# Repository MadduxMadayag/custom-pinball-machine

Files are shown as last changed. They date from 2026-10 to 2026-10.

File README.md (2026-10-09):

# Custom Arduino Pinball Machine

**A fully assembled, SpongeBob-themed pinball machine combining embedded control, sensor interfacing, electromechanical actuators, and custom mechanical design.**

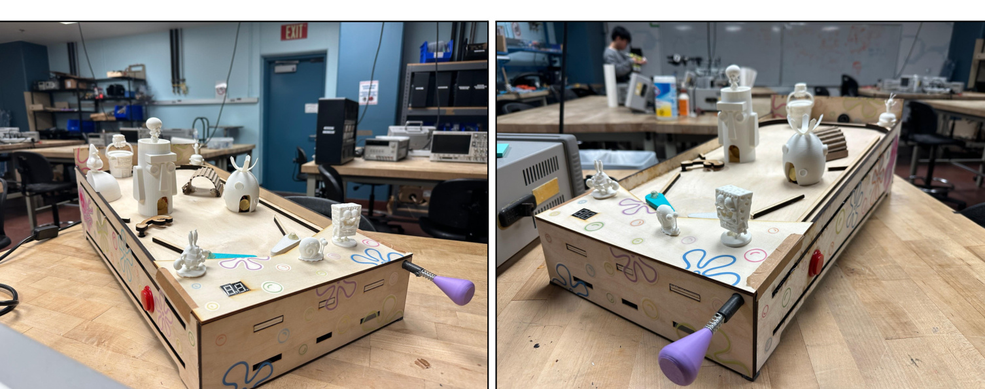
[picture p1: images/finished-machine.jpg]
Completed tabletop pinball machine


## Overview

Designed and built a tabletop pinball machine for **ECE 115**. The system uses an Arduino to coordinate player-controlled solenoid flippers, impact-based scoring, infrared ball detection, a servo-operated ball-return gate, animated obstacles, audio feedback, and a multiplexed two-digit score display. The playfield and mechanical assemblies were developed in **SolidWorks** and fabricated with plywood and 3D-printed components.

The project brings together **circuit design, embedded programming, mechanical CAD, fabrication, integration, and functional testing**.

## Features

| Subsystem | Implementation |
| --- | --- |
| Player controls | Two push buttons and solenoid-actuated flippers |
| Ball launching | Spring-loaded plunger |
| Scoring | Piezoelectric impact sensors inside character houses and an IR beam sensor at the Krusty Krab |
| Ball return | Optical drain detection and servo-driven gate mechanism |
| Moving obstacles | DC motor and RC servo mechanisms |
| Feedback | DFPlayer Mini audio playback and two multiplexed seven-segment displays |
| Controller | Arduino sketch implementing sensor processing, scoring, debouncing, and game-state logic |
| Mechanical design | SolidWorks assemblies, plywood structure, and printed figures |

## Finished Build

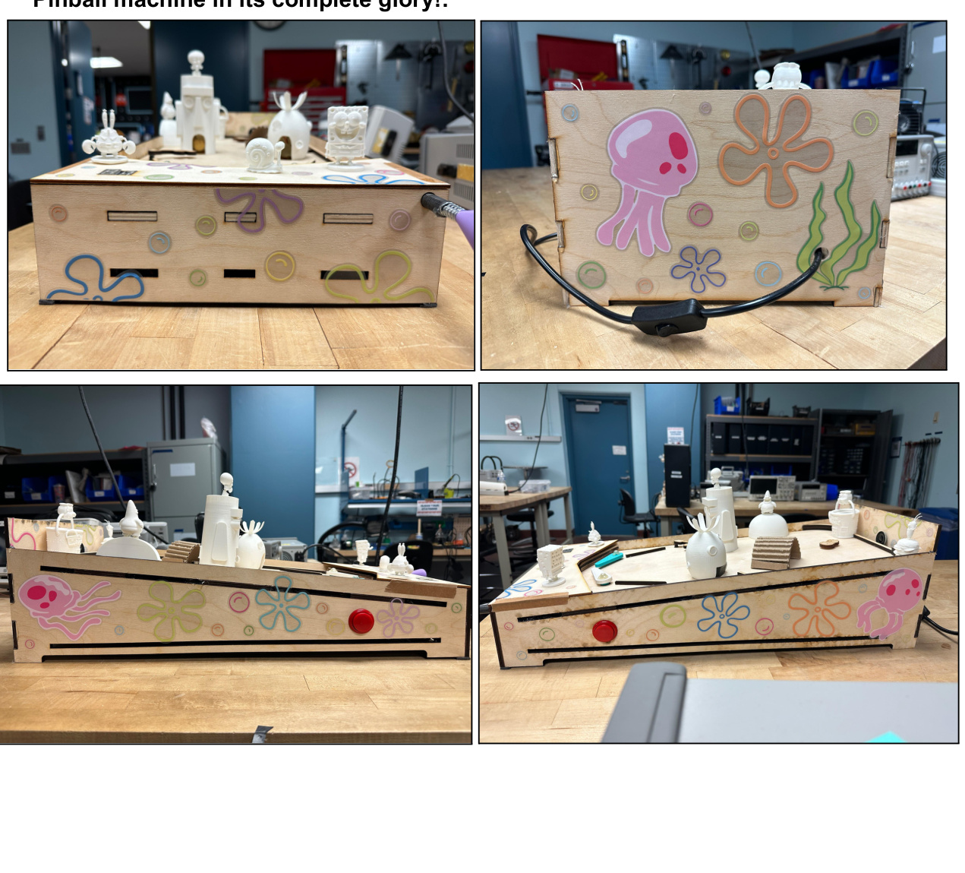
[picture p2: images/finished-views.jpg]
Final machine from multiple angles


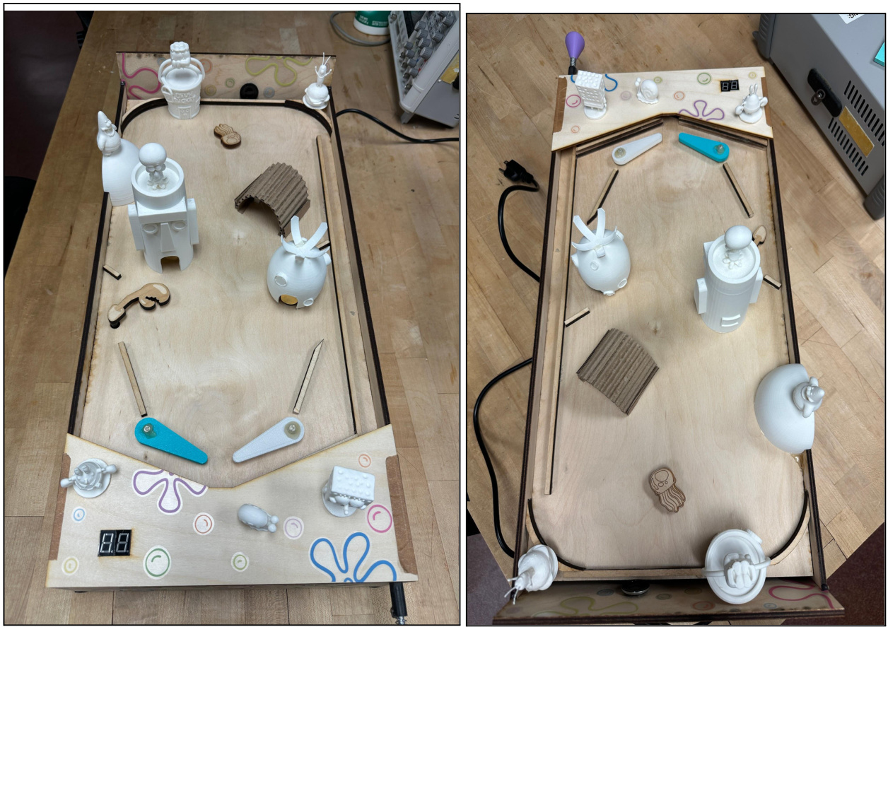
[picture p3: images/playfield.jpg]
Top-down playfield


The sloped playfield uses flippers and themed obstacles to keep a launched ball in play. The design also includes a physical ball launcher, a gate for ball reloading, and an accessible electronics area underneath the playfield.

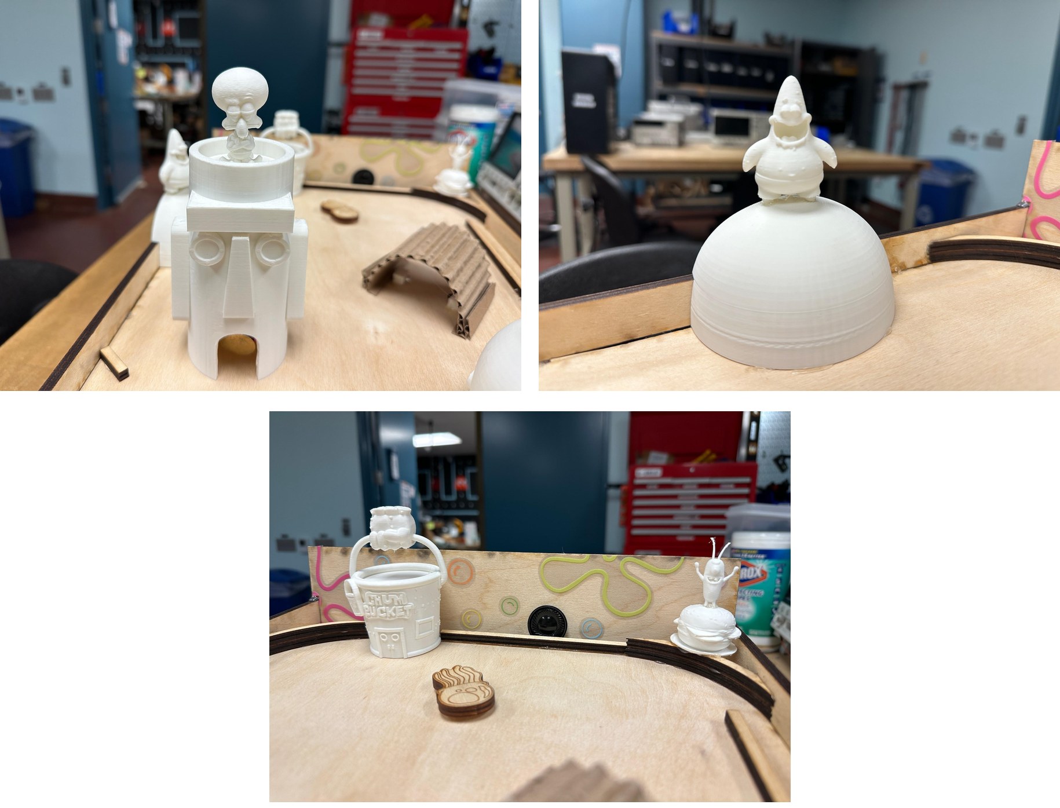
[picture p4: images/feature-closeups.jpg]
Close-ups of themed obstacles and scoring features


## Electrical and Embedded Design

The Arduino reads the **piezo** and **infrared** sensors to detect scoring events and ball movement. MOSFET driver stages switch the solenoids and motor, with flyback diodes used for inductive-load protection. The IR interface uses signal filtering and comparator hysteresis to help reject false triggers. A **DFPlayer Mini** provides audio cues, while the score is shown on two multiplexed seven-segment displays.

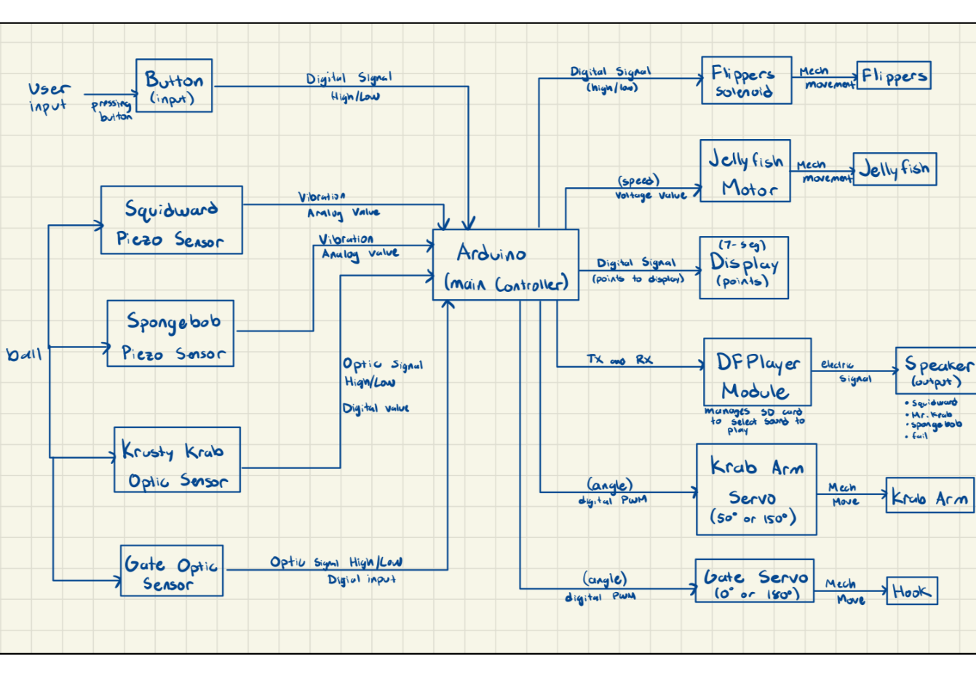
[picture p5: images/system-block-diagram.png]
System block diagram


**Actuation circuits — DC motor and solenoid flippers**

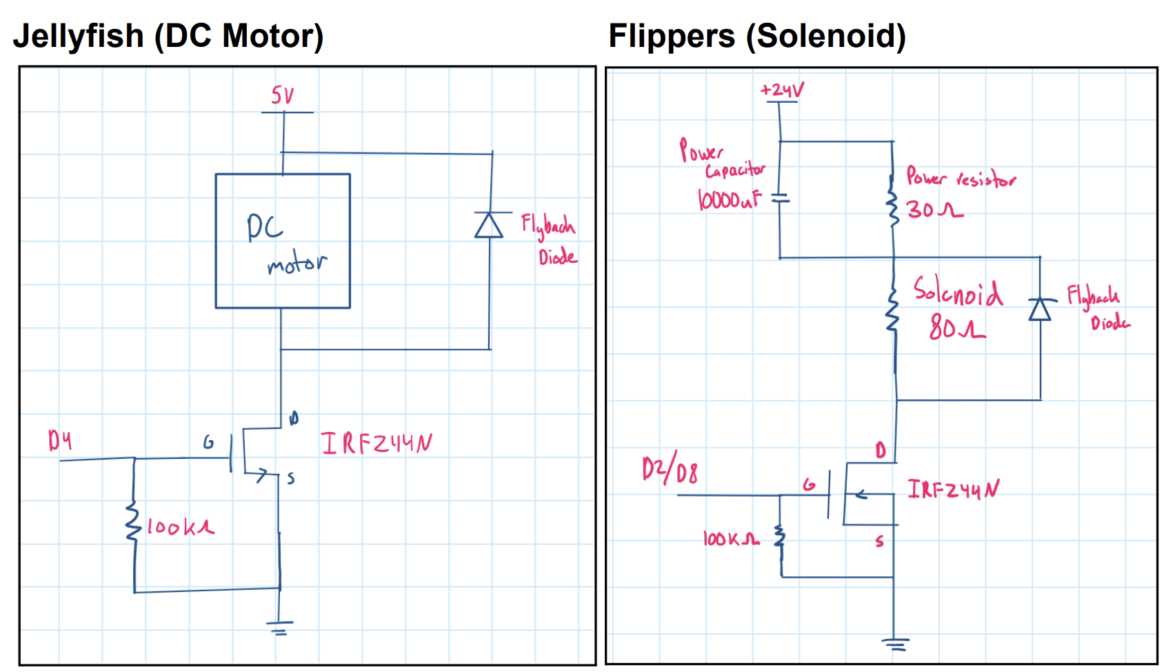
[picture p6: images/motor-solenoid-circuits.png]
Actuator circuit diagrams


**Sensor, audio, and display interface diagrams**

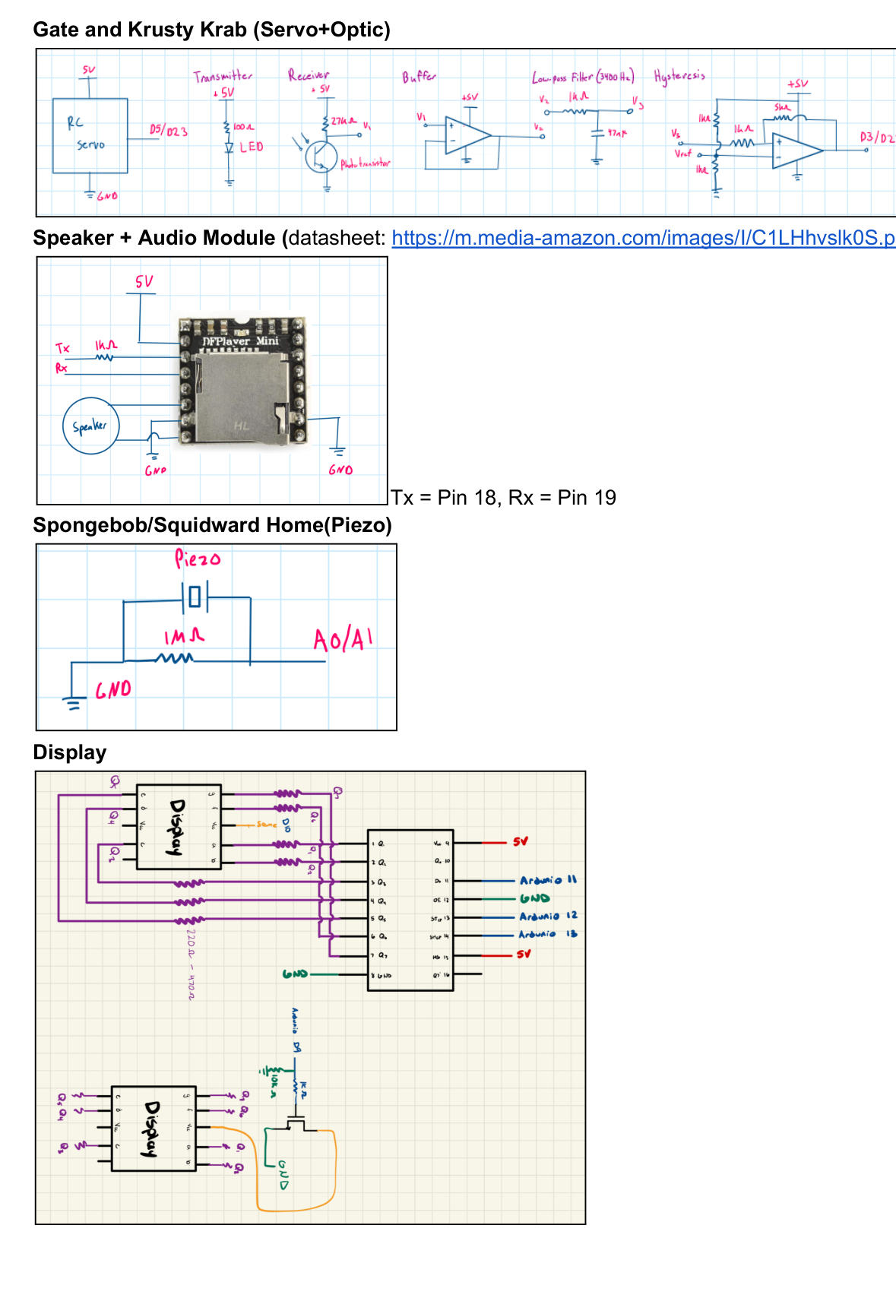
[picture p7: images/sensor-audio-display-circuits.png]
Sensor and display diagrams


See the original [`firmware/Pinball_code.ino`](firmware/Pinball_code.ino) for control logic. The sketch depends on the Arduino `Servo` library and the `DFRobotDFPlayerMini` library; hardware-specific pin assignments are defined near the top of the file.

## Mechanical Design

The team modeled the playfield, flippers, ball launcher, and moving mechanisms in **SolidWorks** before constructing the plywood enclosure and assembling the printed figures. Native assembly and part files are preserved in [`mechanical/`](mechanical/).

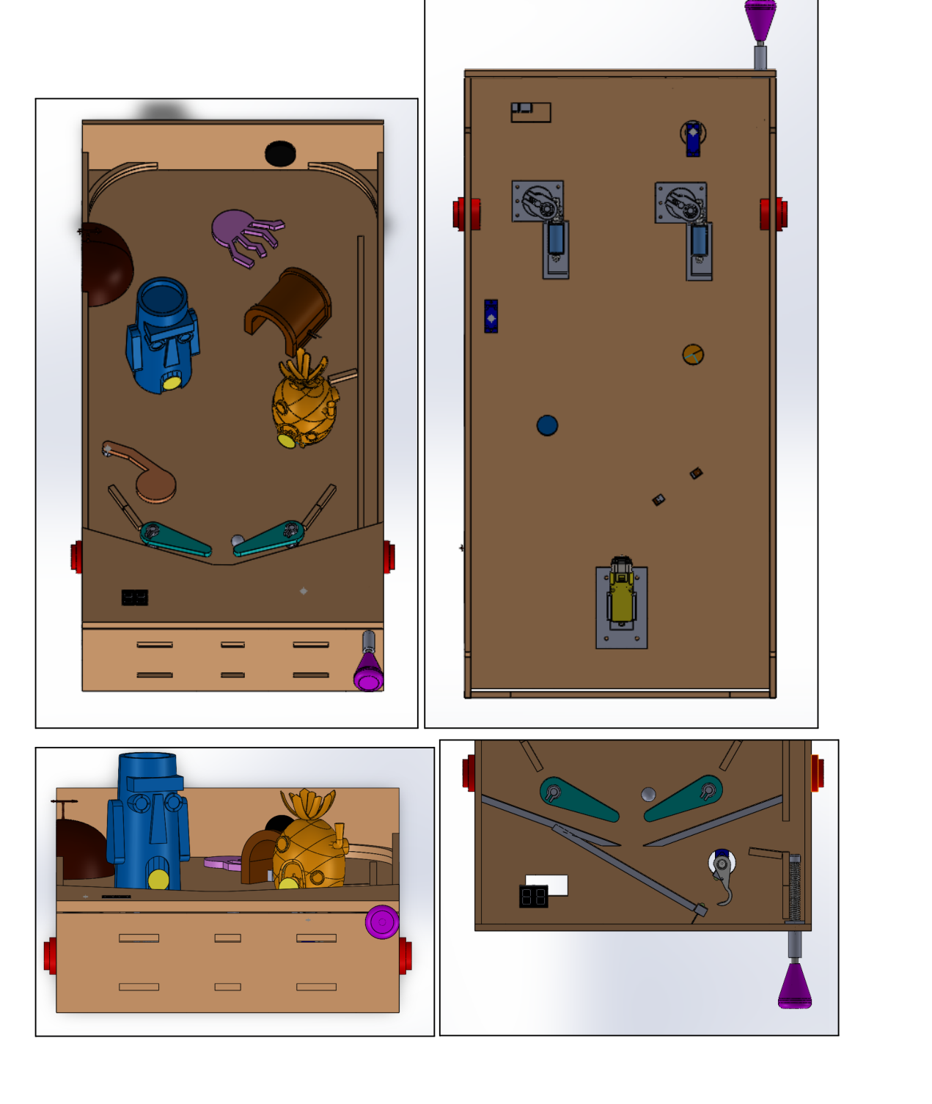
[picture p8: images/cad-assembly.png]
CAD assembly views


**Electronics mounted beneath the playfield**

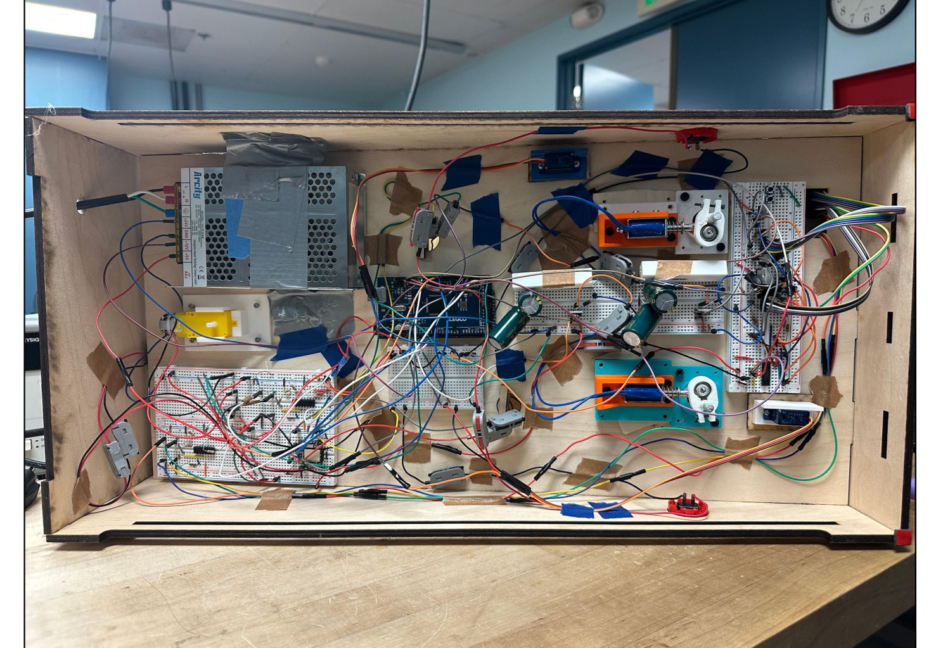
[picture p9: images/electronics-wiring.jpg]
Wiring and electronics mounted under the machine


The electronics were attached to the underside of the playfield and enclosure sides rather than using separate breadboard mounts, keeping wiring shorter and the hardware accessible during integration.

## Game Control

The Arduino coordinates scoring, flipper movement, ball detection, and servo-based reloading through game-state logic. The report documents the high-level state-machine diagrams for the pinball machine, score display, flipper controls, and player flow.

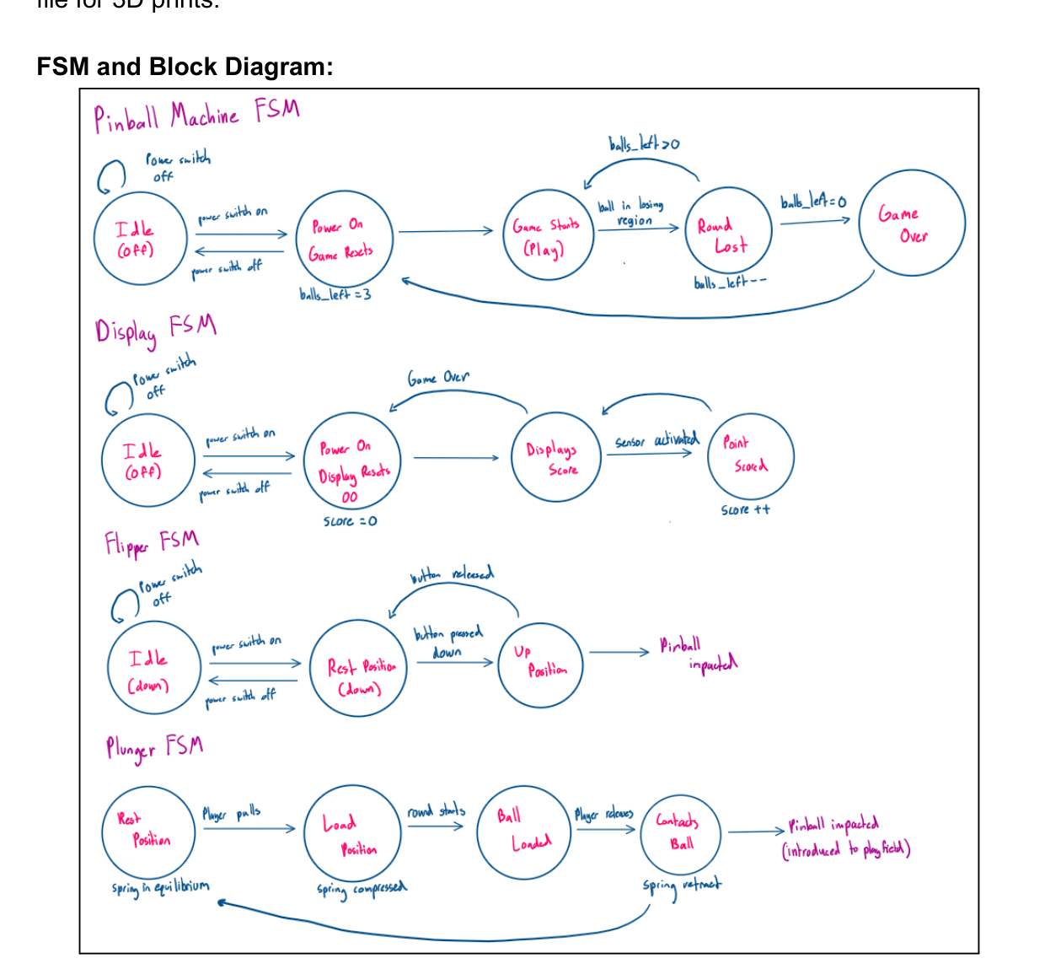
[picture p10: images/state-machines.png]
Finite-state-machine diagrams


The optical and servo gate mechanism was also designed and evaluated as a dedicated subsystem.

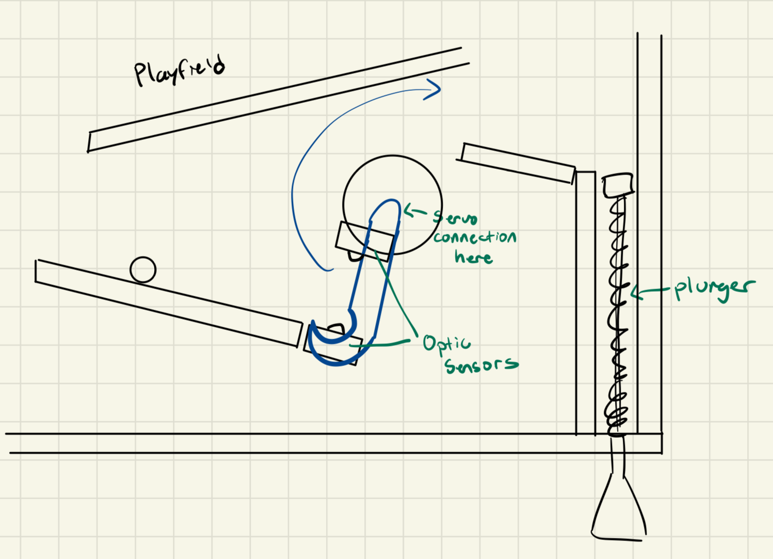
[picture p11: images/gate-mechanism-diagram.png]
Gate mechanism design diagram


## Testing and Results

The final team report documents a **completed system evaluation**, including the following functional observations:

- **Scoring:** Impacts on the piezo-equipped houses updated the score. The Squidward sensor required more force than the SpongeBob sensor.
- **Ball return:** The gate successfully collected/reloaded a drained ball in the documented test.
- **Round handling:** The report records a three-cycle gate/round test.
- **Playfield design:** Added obstacles reduced immediate ball losses and extended rounds during playtesting.

These are qualitative functional results from the final report, not quantified reliability or performance benchmarks. See the [final report](documentation/final-report.pdf), especially its test matrix on **pages 5–6**.

## Project Files

```text
custom-pinball-machine/
├── README.md
├── images/             # Selected photographs and figures from the final PDF
├── firmware/           # Original Arduino sketch
├── mechanical/         # SolidWorks assemblies and part files
│   └── printed-figures/# Original 3MF assets (check third-party licensing)
└── documentation/      # Original 13-page final report
```

**Image sources:** Finished-machine and playfield photos are from report **pages 6–7**; close-up figures from **page 2**; underside wiring from **page 3**; CAD from **page 8**; FSM diagrams from **page 9**; electrical diagrams and system overview from **pages 10–11**; and gate mechanism diagrams from **page 5**. The images are included separately for easier viewing on GitHub.

## Contributors

**Maddux Madayag and Eric Zheng** — ECE 115 team project.

## Notes

- The firmware is preserved as provided. It was designed for the team's original controller, pinout, wiring, and audio assets; this repository is **not** a plug-and-play kit.
- The **sound files are not included**, and hardware-specific libraries and dependencies must be installed separately.
- The `.SLDPRT` / `.SLDASM` files may require SolidWorks or compatible software, and all their referenced components must be available for assemblies to resolve.
- Some themed `.3mf` figures may have external authors or separate licenses; verify permissions and attribution before public reuse.

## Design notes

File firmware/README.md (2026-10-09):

# Arduino Firmware

`Pinball_code.ino` is the original team sketch, preserved without modifications.

## Dependencies
- `Servo.h` — Arduino Servo library
- `DFRobotDFPlayerMini.h` — DFRobot DFPlayer Mini library

The firmware uses `Serial1` for the audio module and pin definitions at the start of the sketch. Choose a board with the required pins and hardware serial interface, and check those pin definitions against the wiring diagrams in `documentation/final-report.pdf` before flashing. The SD card audio files referenced by `playFolder()` are not included in this repository.

This is an archive of the working course design, **not a validated portable build configuration**. The final report records system testing; no automated compilation or hardware test is included here.

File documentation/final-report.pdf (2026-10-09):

Eric Zheng | Maddux Madayag
A17338793 | A17444726
ECE115 - Module5

Google Drive folder containing files: https://drive.google.com/drive/folders/1A8mDtq7jwpapd6mcWQVZRQ9MVMisnB0y?usp=sharin g (https://drive.google.com/drive/folders/1A8mDtq7jwpapd6mcWQVZRQ9MVMisnB0y?usp=sharing)

# 5.2.1 Add the proposed functionality to the pinball machine

## Completed additional function

Added functions: more obstacles, decals*, piezo circuitry, gate mechanism, more 3D printed figures, and compacted wire system
*reference final pinball machine photos

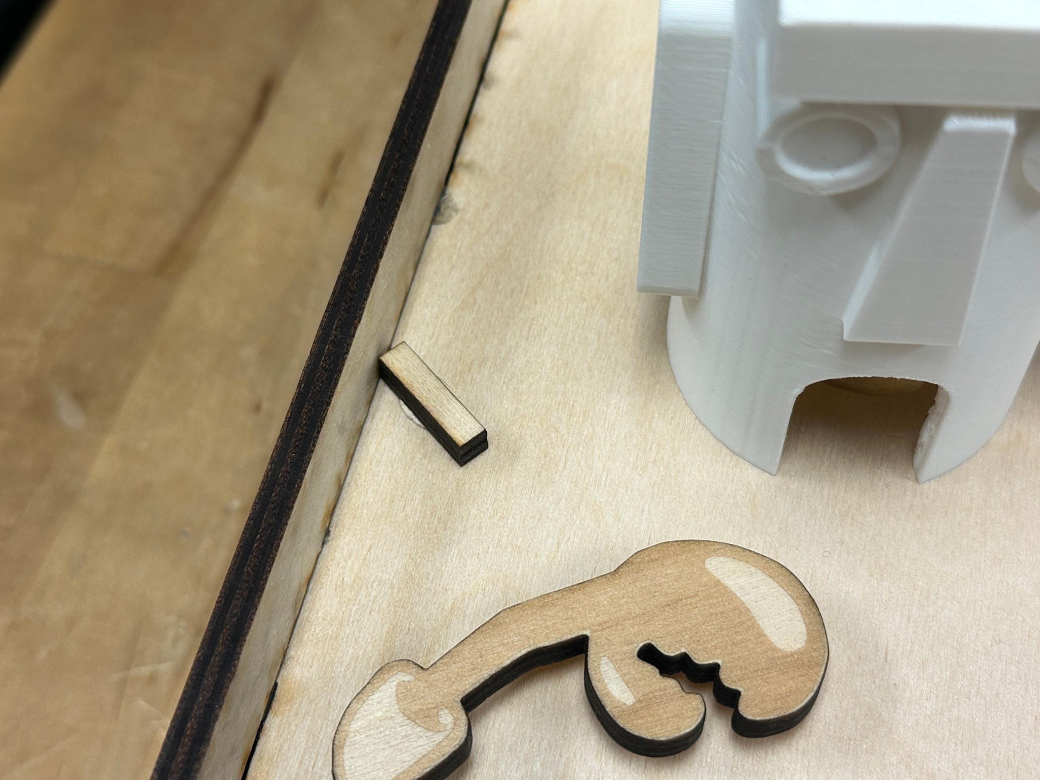
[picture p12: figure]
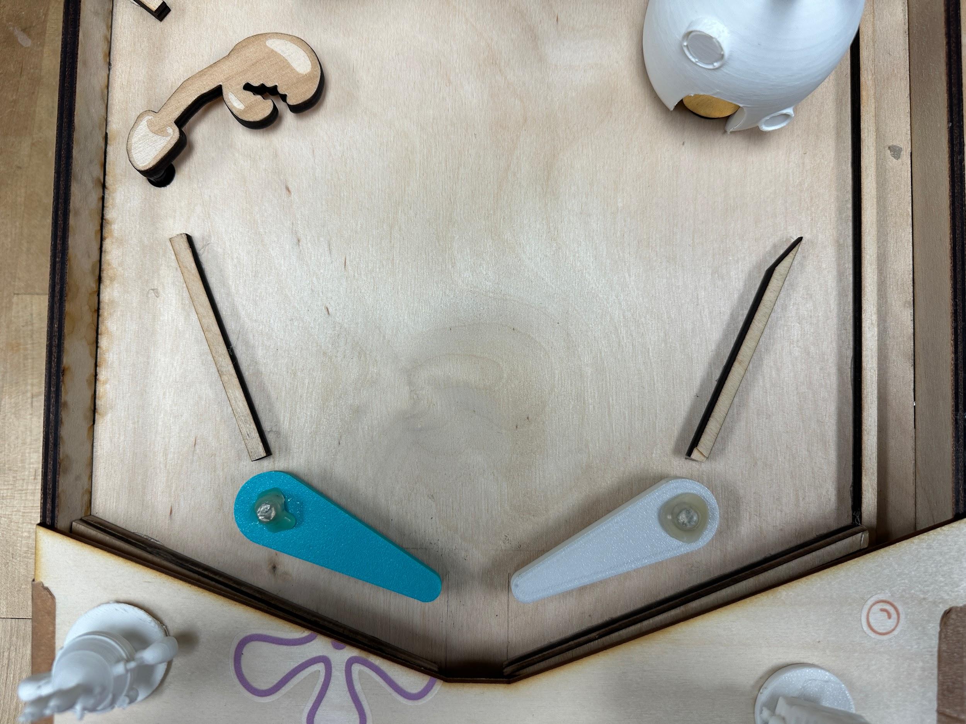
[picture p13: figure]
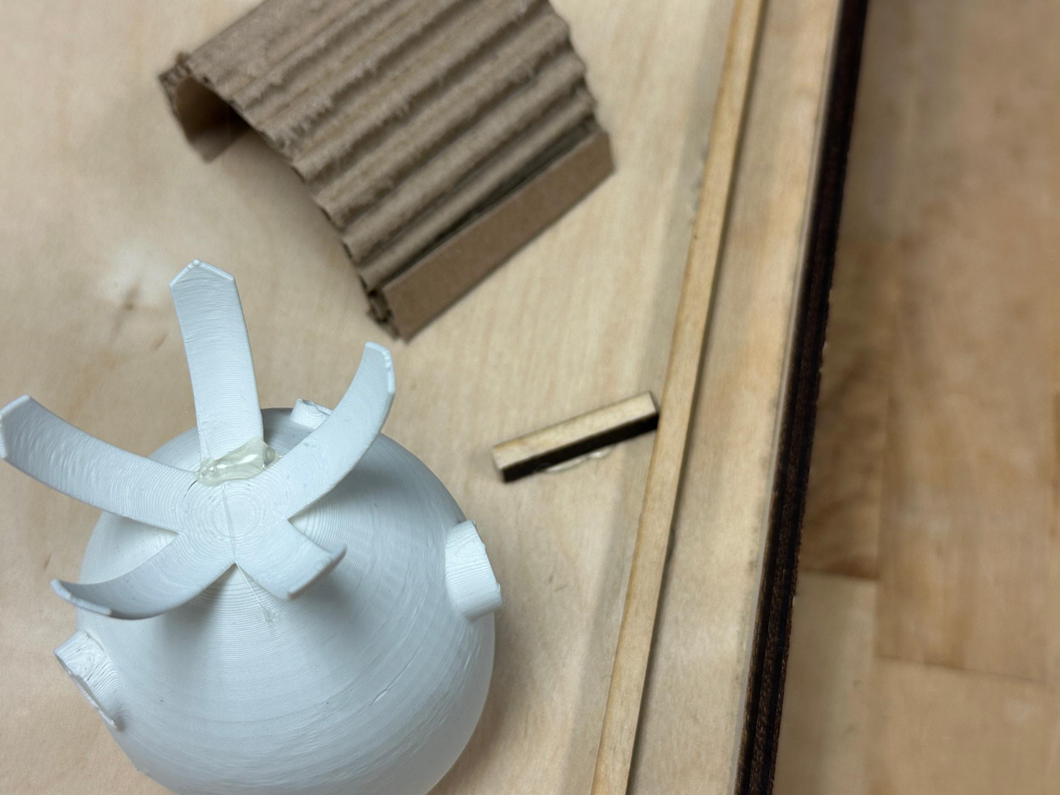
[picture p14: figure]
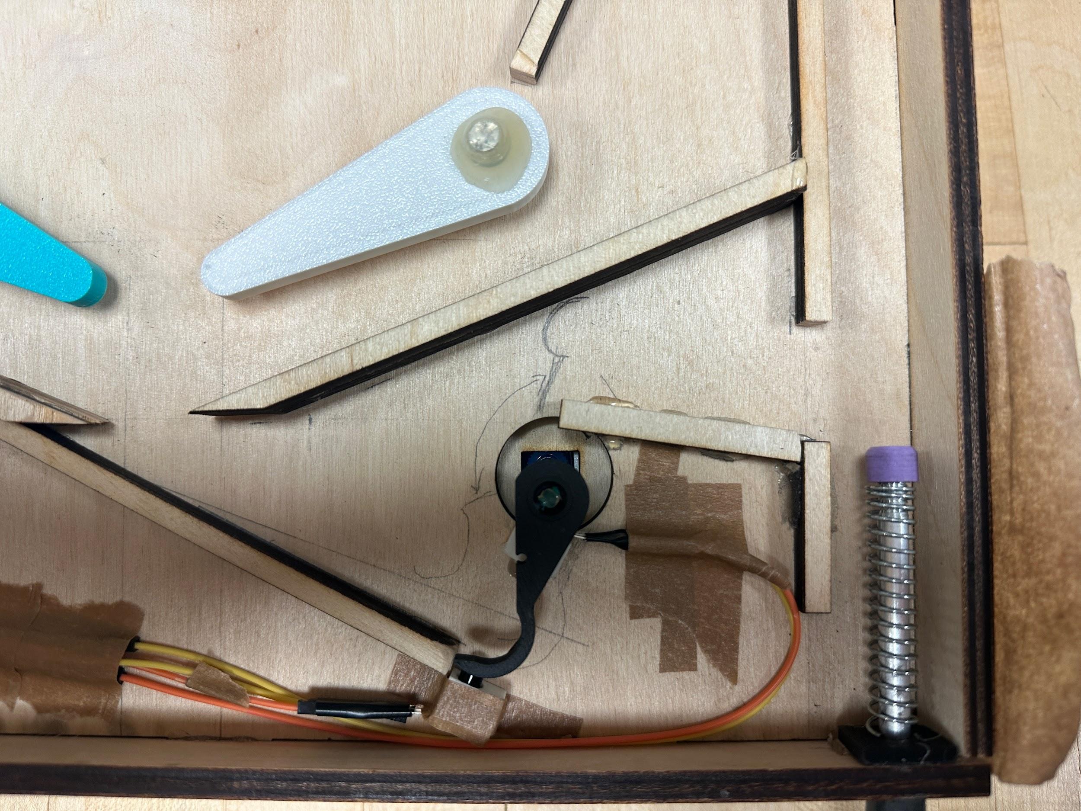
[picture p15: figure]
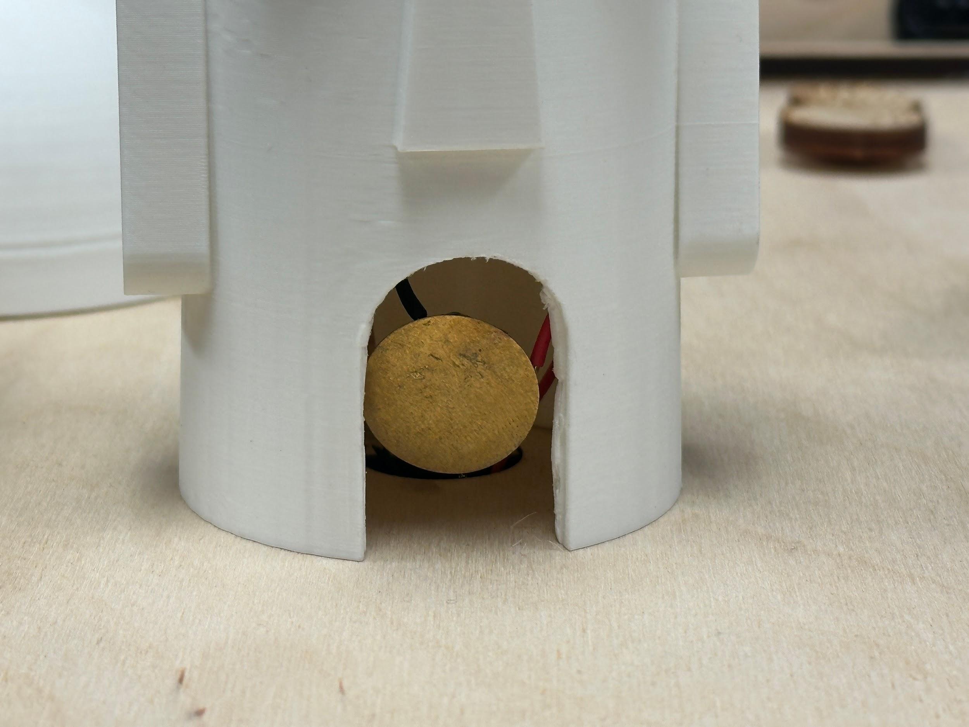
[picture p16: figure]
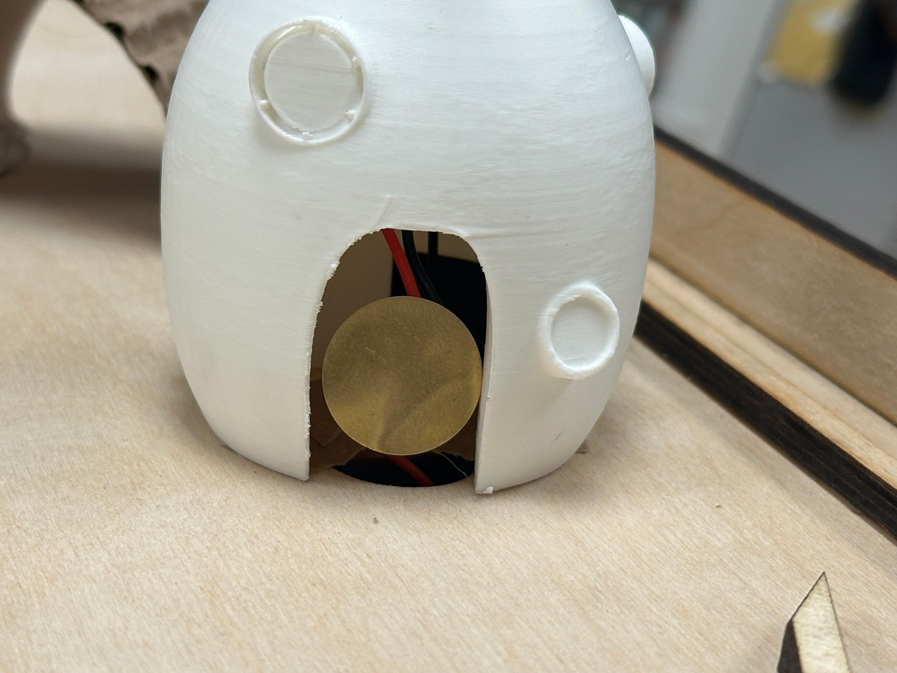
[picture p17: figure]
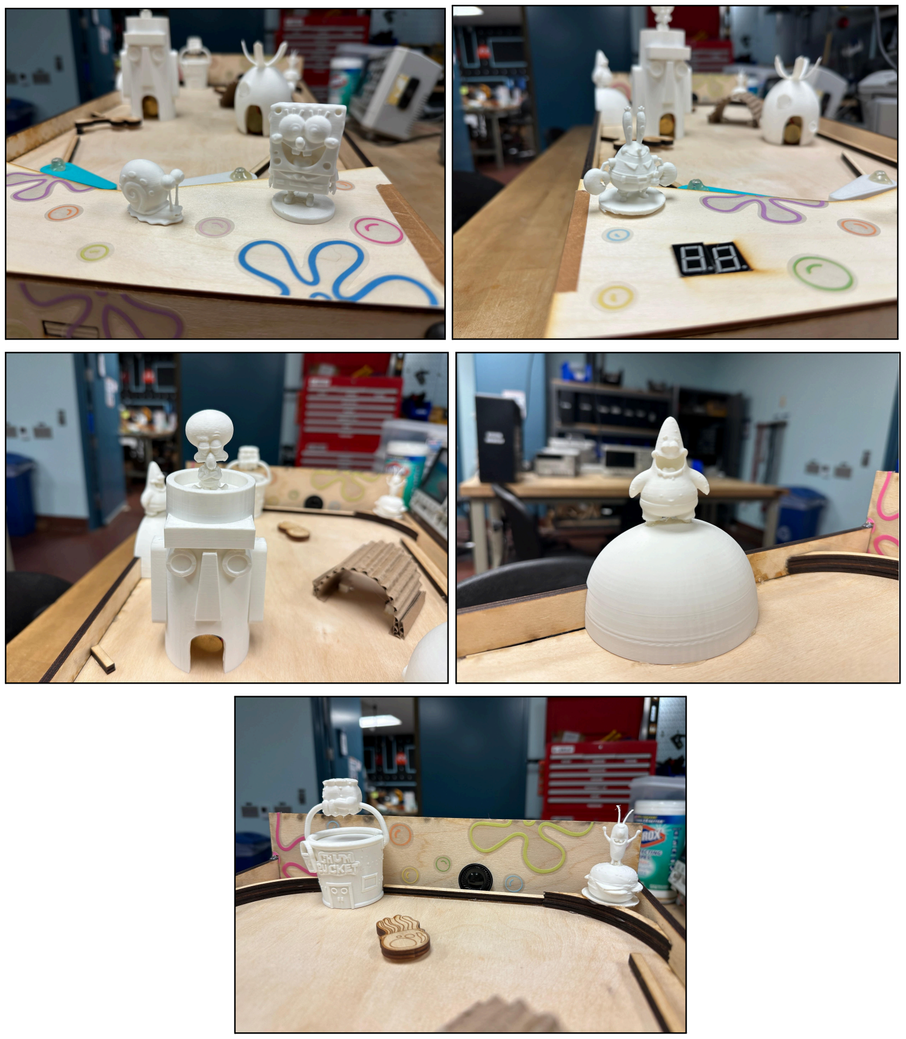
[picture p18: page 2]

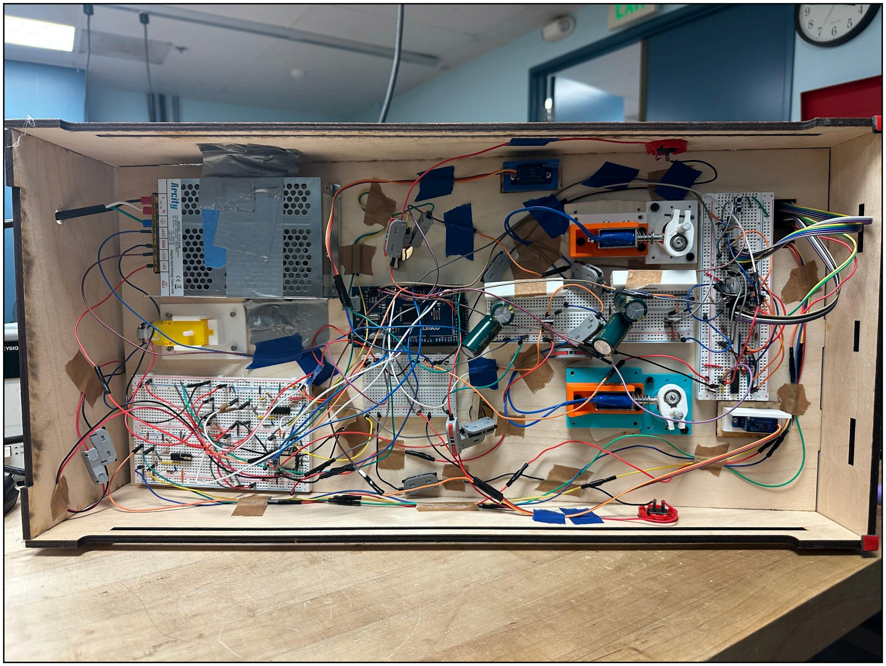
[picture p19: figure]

Additional Functionality Omitted:
- 3D mounts for the arduino and breadboards: required longer wires for routing and created the challenge of switching between working on the top (playfield) and circuits. Switches approach by containing electronics by attaching them to the opposite of the playfield and sides of the pinball machine.
- Paint: Would take too long for paint to dry so we opted to use other techniques to improve the visuals of the pinball machine (more 3D printed figures and decals)

# 5.2.2 Final Presentation / Demo

## Full System Evaluation: Complete

# 5.2.4 Final Writeup

## Final Writeup

### 1. Summarize your additional functionality

Additional Functionality:
We originally proposed the added functionality of 3D printed breadboard and motor holders. However, we found that it was easier to mount the electronic components to the opposite side of the playfield and the sides, as this kept the electronics accessible when working on the top and shortened the wire lengths. One additional functionality we implemented was adding extra walls to prevent the ball from easily reaching the losing region. Furthermore, we were able to integrate piezo sensors into our system and develop an RC servo arm to load the ball into the plunger. In our proposal, we also planned to paint the pinball machine, but due to time constraints we were not able to complete this. Instead, we 3D printed SpongeBob themed figures and applied decals to make the system more visually appealing.

Requirements:
1. Flipper obstacles make losing harder
2. Piezo Sensor sensing ball well
3. Automatic gating
4. Decal doesn’t obstruct playfield Materials:
- 0.275” plywood: Amazon (https://www.amazon.com/s?k=1%2F4+inch+plywood)
- Decals: Amazon (https://www.amazon.com/dp/B0FD7F2FVL)
- 3D and laser prints: Free from ECE Makerspace
- Model files:
https://drive.google.com/drive/folders/1kOY6Z7JHsXjdMh7Nvi-niw0s6ZCll8pl?usp=sharing (https://drive.google.com/drive/folders/1kOY6Z7JHsXjdMh7Nvi-niw0s6ZCll8pl?usp=sharing)
Design:
Piezo

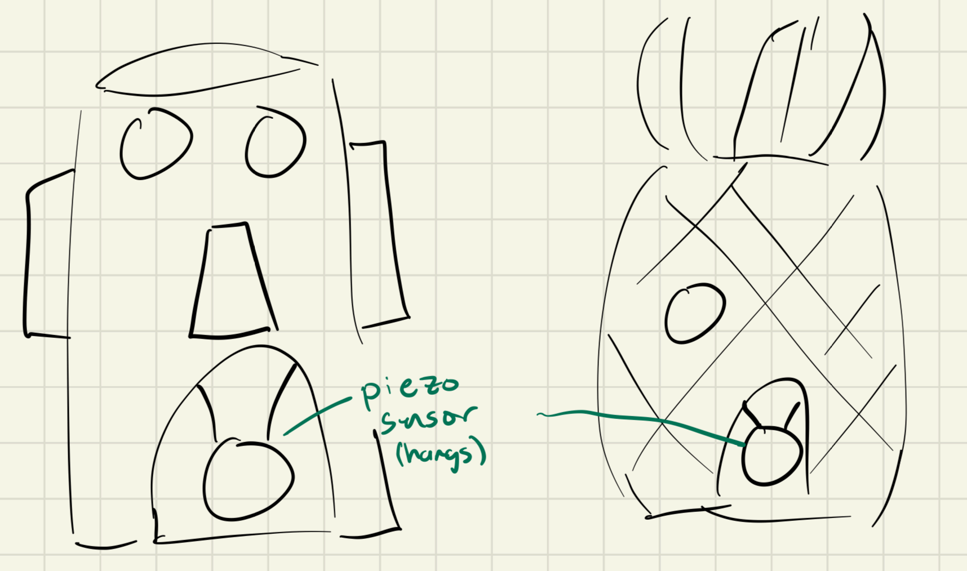
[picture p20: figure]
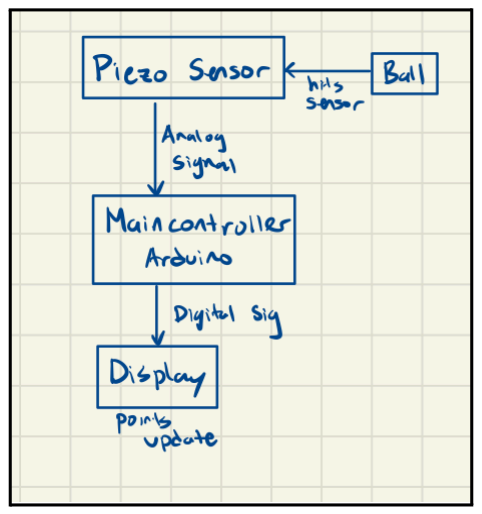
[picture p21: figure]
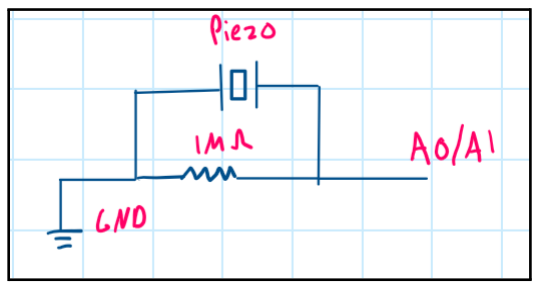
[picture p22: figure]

Gating Mechanism

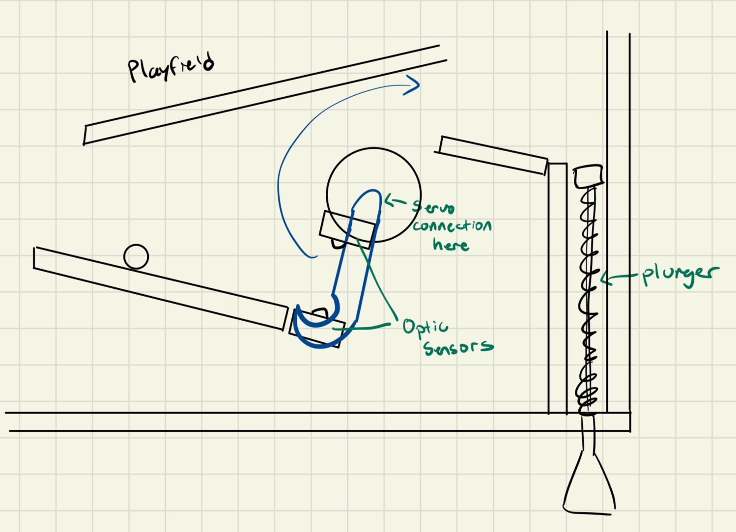
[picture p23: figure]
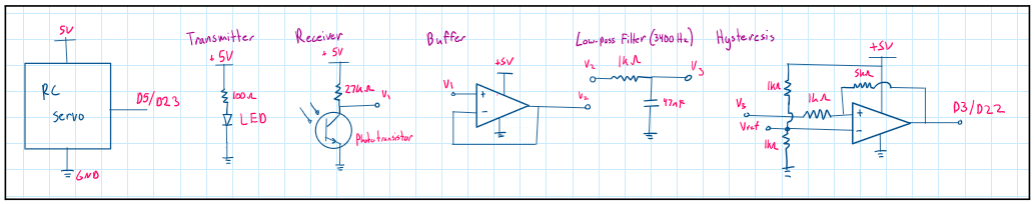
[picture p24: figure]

Trace Matrix:

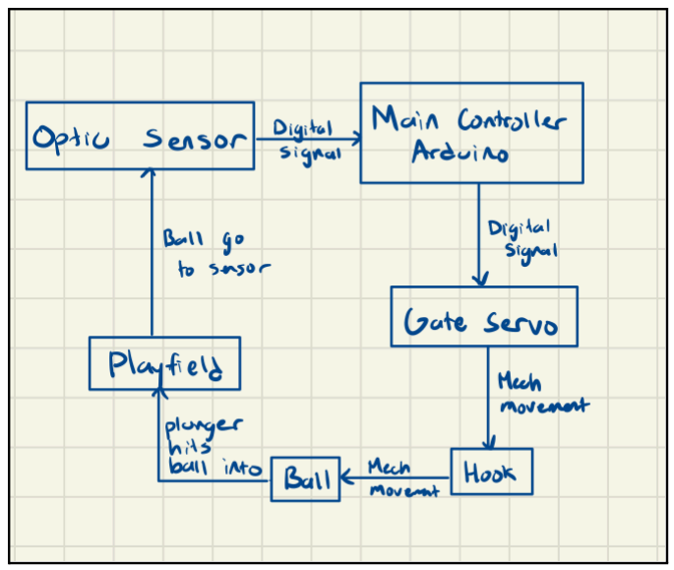
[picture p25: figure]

Specification number | Specification description | Test to perform | Relevant requirement | Specification (units) | Measured value (units)
1 | Functionality | Launch the ball using the flipper into the piezo sensors, see if score updates. | 2 | Yes/No (Y/N) | Y, the squidward sensor seems to be less sensitive than spongebob and requires more force for it to update the display.
2 | Functionality | Let the ball fall towards the bottom of the board and see if the gating mechanism will pick up the ball and load it in the launcher. | 3 | Yes/No (Y/N) | Y
3 | Functionality | Let the gating mechanism load the ball 3 times, and let the ball fall towards the gating mechanism again, and see when the gating mechanism stops. | 3 | count | 3

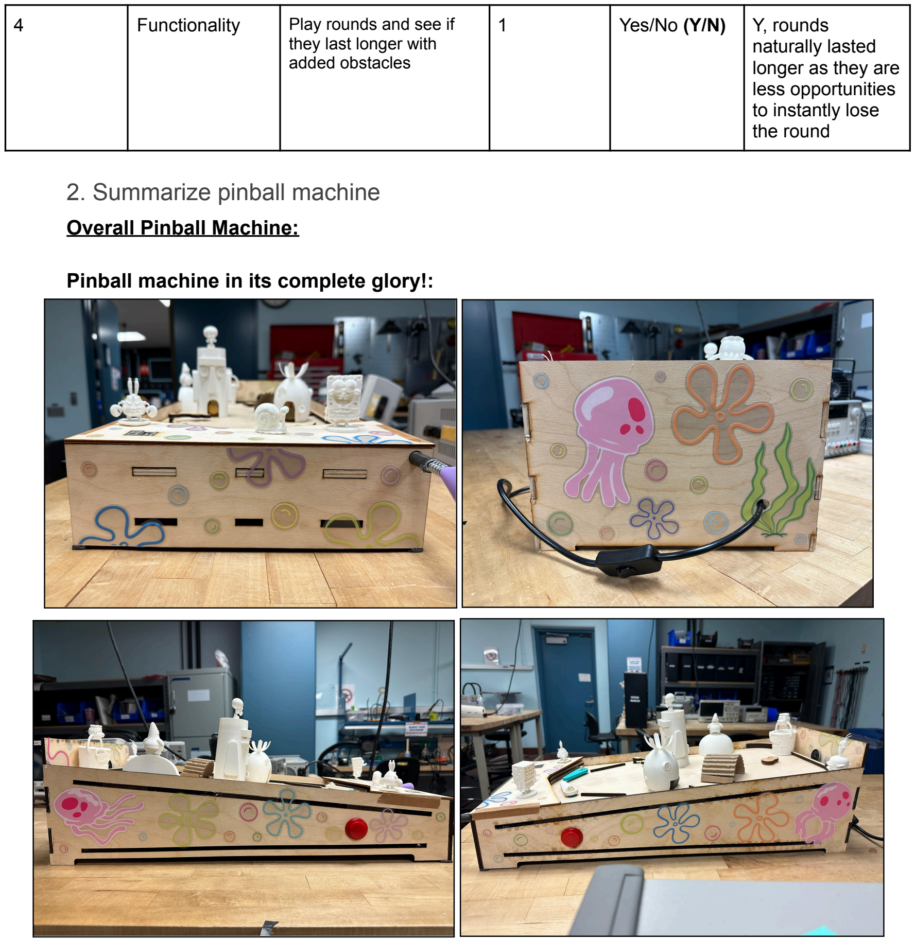
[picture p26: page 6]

4 | Functionality | Play rounds and see if
they last longer with
added obstacles
1 | Yes/No (Y/N) | Y, rounds
naturally lasted
longer as they are
less opportunities
to instantly lose
the round

### 2. Summarize pinball machine

Overall Pinball Machine:

Pinball machine in its complete glory!:

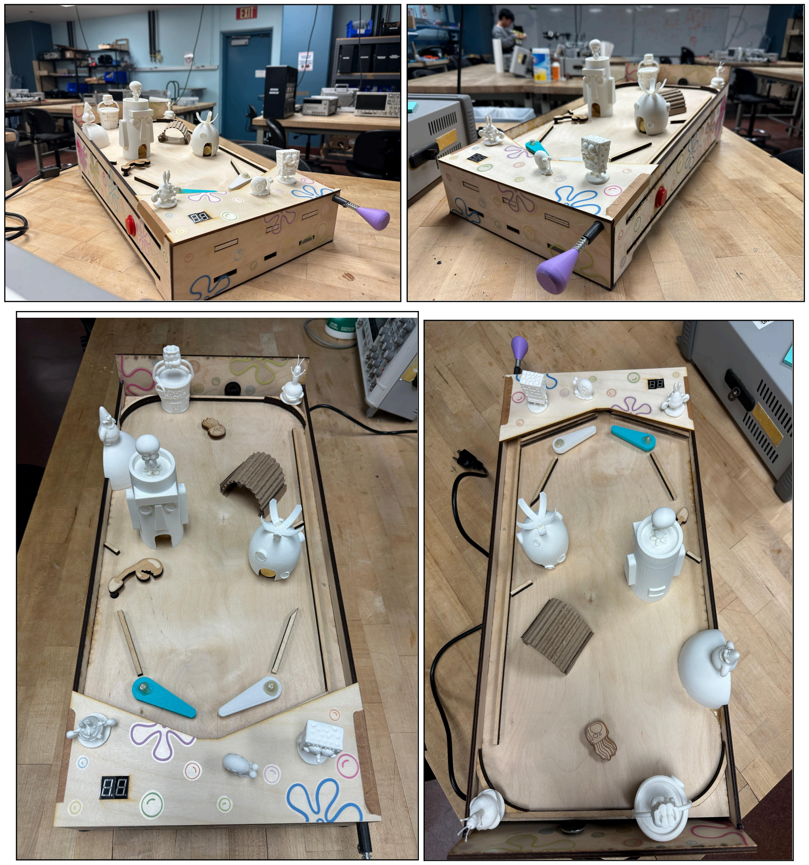
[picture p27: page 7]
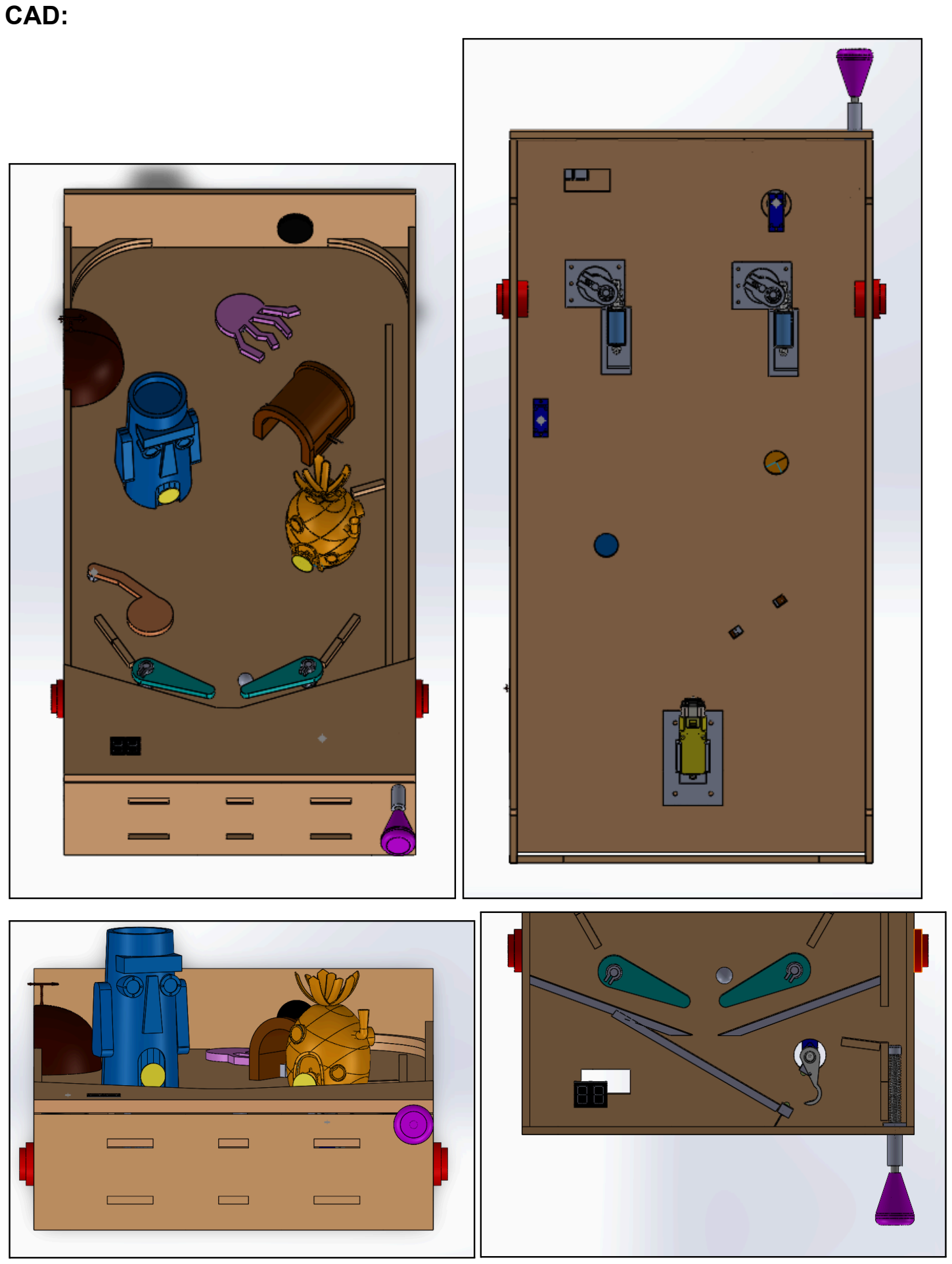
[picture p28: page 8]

CAD:

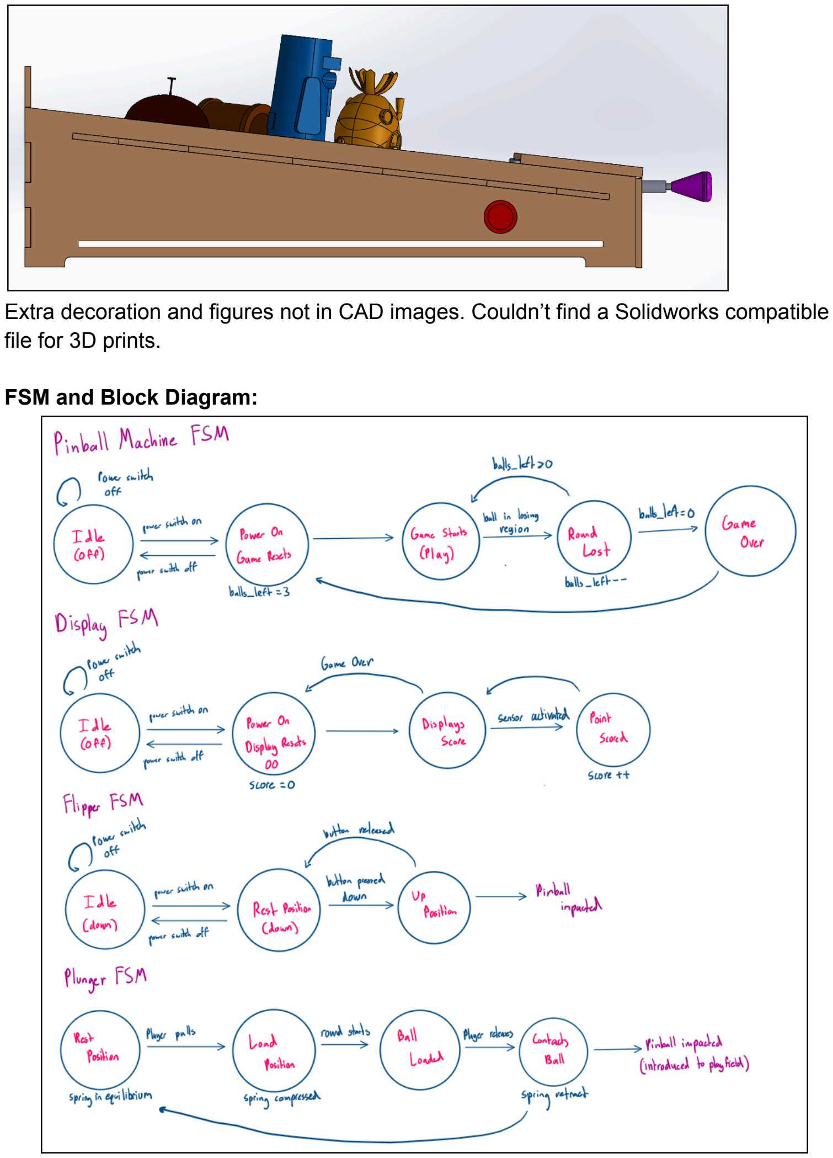
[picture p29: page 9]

Extra decoration and figures not in CAD images. Couldn’t find a Solidworks compatible file for 3D prints.

FSM and Block Diagram:

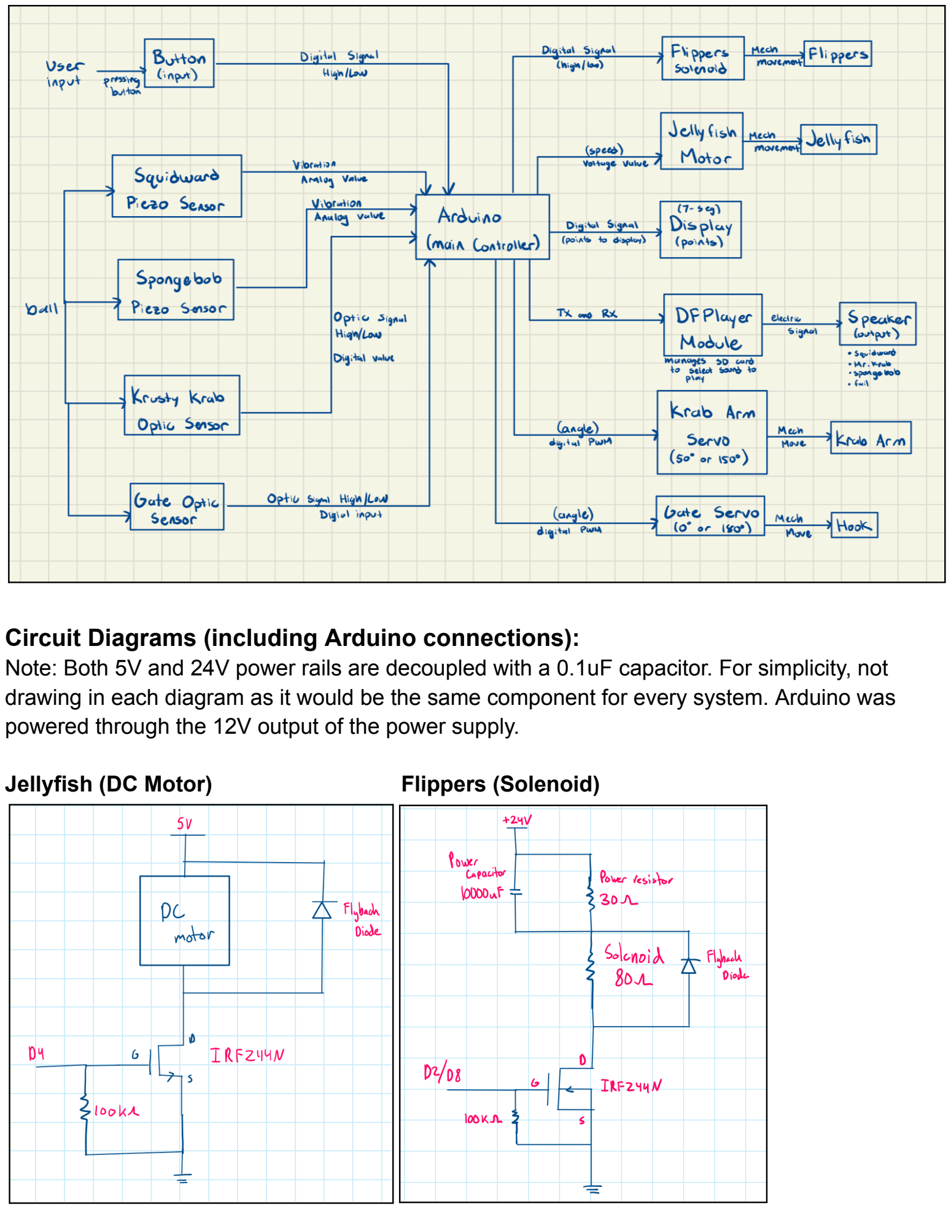
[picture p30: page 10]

Circuit Diagrams (including Arduino connections):
Note: Both 5V and 24V power rails are decoupled with a 0.1uF capacitor. For simplicity, not drawing in each diagram as it would be the same component for every system. Arduino was powered through the 12V output of the power supply.
Jellyfish (DC Motor) | Flippers (Solenoid)

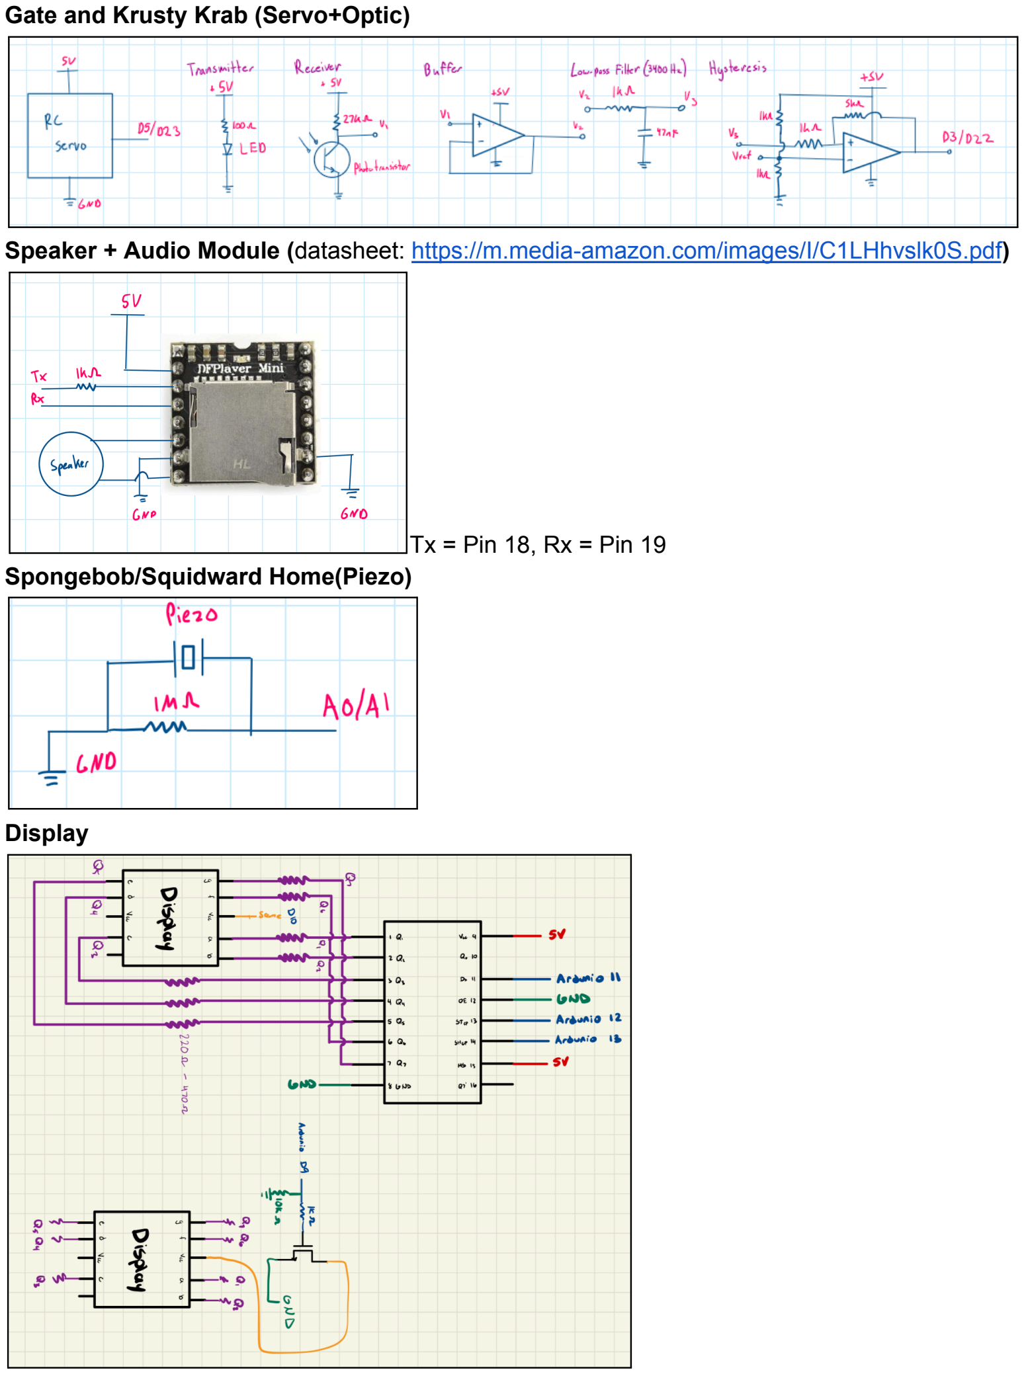
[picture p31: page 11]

Gate and Krusty Krab (Servo+Optic)

Speaker + Audio Module (datasheet: https://m.media-amazon.com/images/I/C1LHhvslk0S.pdf)

Tx = Pin 18, Rx = Pin 19
Spongebob/Squidward Home(Piezo)

Display

Pinball Machine Summary:
Our pinball machine was constructed primarily from plywood with several 3D printed components and electronics and hardware provided by the class. The playfield is slanted so the ball naturally rolls towards the losing region. A spring loaded plunger launches the ball onto the playfield, and two solenoid driven flippers allow the player to redirect the ball and keep it in play. Obstacles on the board include plywood walls, 3D printed SpongeBob themed houses, and plywood shapes of a jellyfish and Mr. Krab’s arm are attached to an RC servo and DC motor. All components share a common ground with bypass capacitors across the power rails to stabilize supply. Comparing the CAD model with the final built machine highlights the importance of accurate modeling when translating a design into a physical system.

Points are earned through several sensor systems. Piezo sensors inside Squidward’s and SpongeBob’s houses detect impacts from the ball and produce voltage spikes that are read by an Arduino analog input. An IR emitter and receiver inside the Krusty Krab detect when the ball passes between them, awarding points and trigger Mr. Krab’s arm (attached to RC servo) to move between positions. This detection circuit uses an op-amp buffer, low pass filter, and hysteresis comparator to reduce noise and prevent false triggers.

Another IR emitter and receiver pair detects when the ball reaches the losing region, allowing the Arduino to track rounds and reset the game when the ball is reloaded and both flipper buttons are pressed. The DC motor and solenoids are controlled using power MOSFETs so the Arduino can safely switch higher current loads. A pull down connection on the MOSFET gate ensures the device turns off if the Arduino disconnects, and flyback diodes across the motor and solenoids suppress inductive voltage spikes. The solenoid circuit also includes a capacitor and resistor to control activation and safely discharge stored energy.

A DFPlayer Mini audio module plays SpongeBob themed sounds during gameplay, and two seven segment displays are multiplexed using MOSFET switching to show the score. All hardware interfaces with the Arduino, which coordinates sensor inputs and actuator outputs. The block diagram illustrates the connections between components, while the FSM diagram represents the high level game states and transitions that control gameplay.

### 3. Safety, Ethics, and Diversity:

Since we are working with circuits for this project, we ensured that nothing will catch fire from unsafe operation (overheating) or shorting. We made sure to always check the secureness and connection of the wires including a common ground reference point. Multiple wires were connected between subsystem grounds for redundancy. Since the pinball machine involves launching a ball at high speed from a plunger, we implemented several safety measures to prevent potential injuries. Springs were added on both ends of the plunger to better control the launch speed of the ball, and the walls of the machine were built high enough to prevent stray balls from leaving the playfield. We also sanded down any chipped or sharp edges on the machine to reduce the risk of splinters and make it safer for people to handle.We also respected the ECE Makerspace through proper usage of all equipment and following rules for the space.

On ethics, we were mindful of minimizing waste and responsibly using the shared class resources. We returned unused components so that other/future students could use them. We also tested our system carefully before demonstrations to avoid damaging equipment or creating unsafe conditions in the makerspace.

For diversity, our theme is Spongebob, a cartoon that is recognized around the world and familiar to many people. We hope that this theme helps make the project engaging for a broad audience. We also tried to design the machine so that the gameplay is simple and easy to understand, allowing people from different backgrounds or technical experience levels to interact with it.

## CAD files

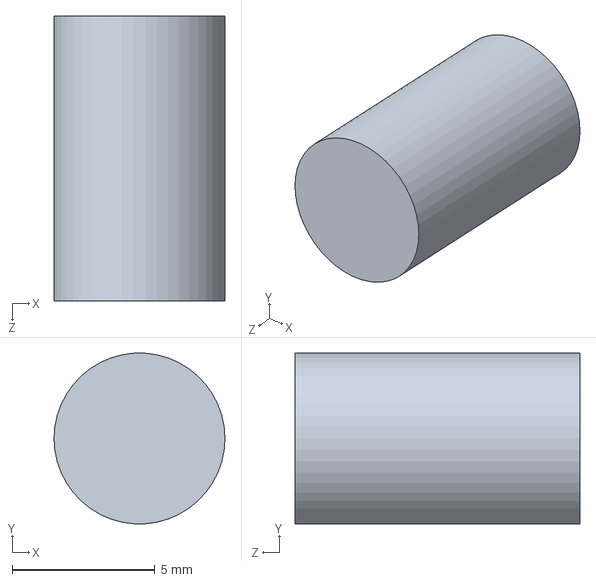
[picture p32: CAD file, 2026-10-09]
mechanical/Flipper/clamp_connect.SLDPRT
6.00 x 5.99 x 10.0 mm

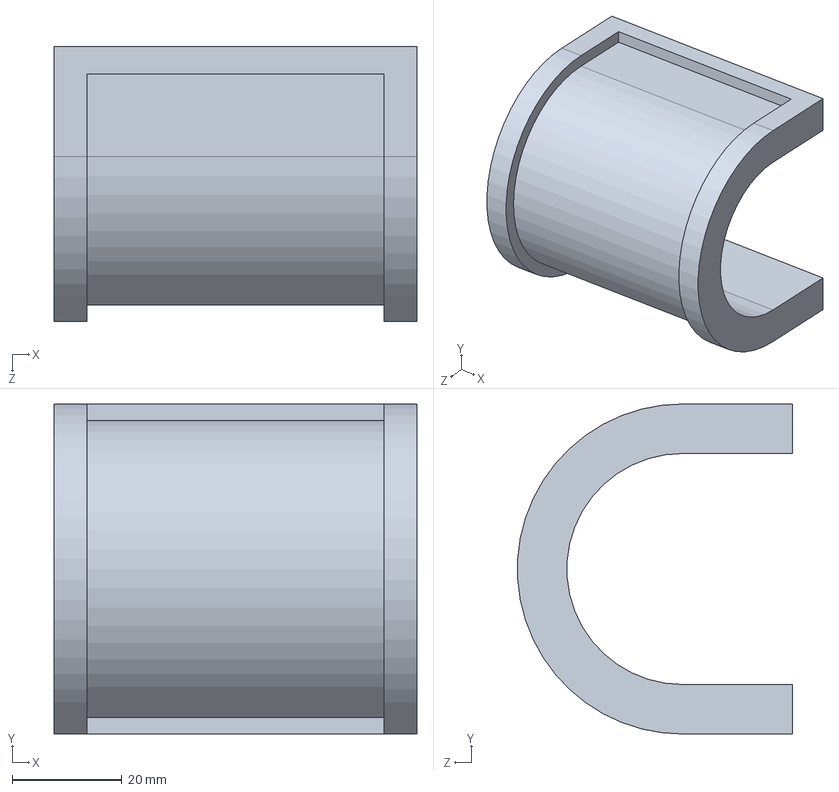
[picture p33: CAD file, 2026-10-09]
mechanical/Houses/krab.SLDPRT
66.0 x 60.0 x 49.9 mm

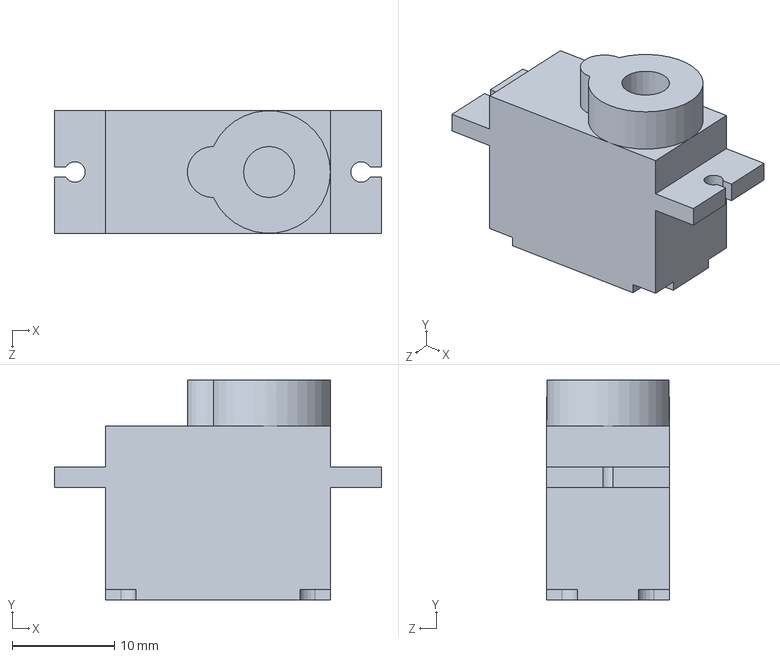
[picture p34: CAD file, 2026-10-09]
mechanical/Krab_Arm/Pieza1.SLDPRT
32.0 x 21.5 x 12.0 mm

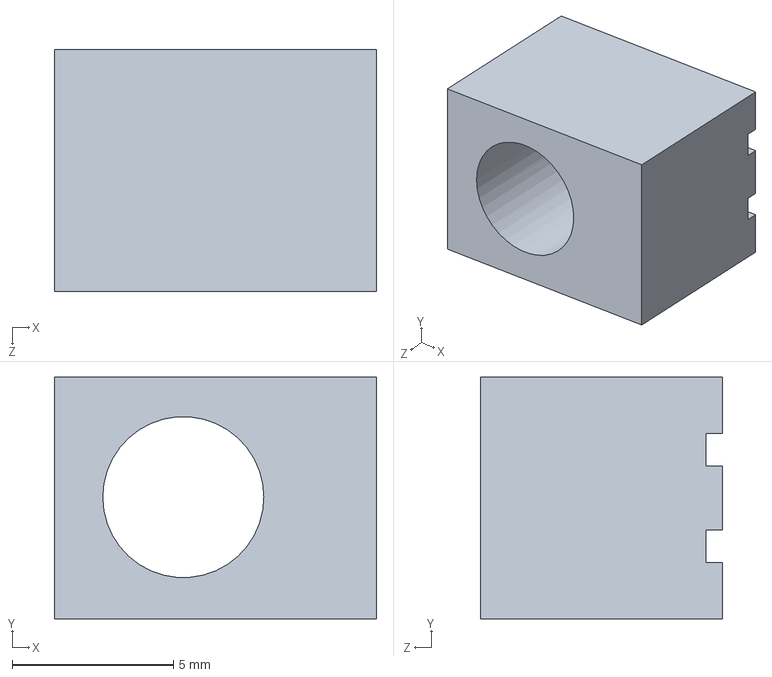
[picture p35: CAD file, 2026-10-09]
mechanical/LEDs/LED_holder.SLDPRT
10.0 x 7.50 x 7.50 mm

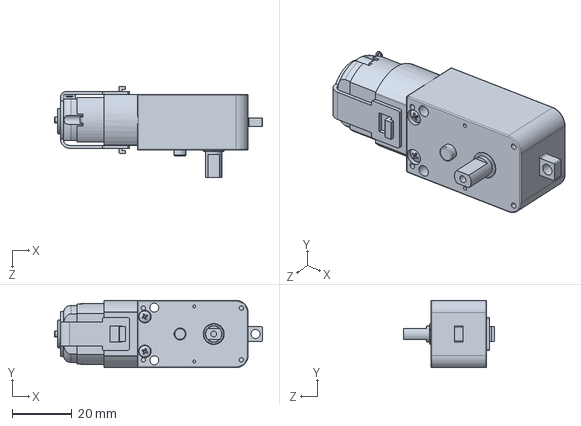
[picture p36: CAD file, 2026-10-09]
mechanical/Motor/motor.SLDPRT
69.5 x 22.4 x 30.5 mm

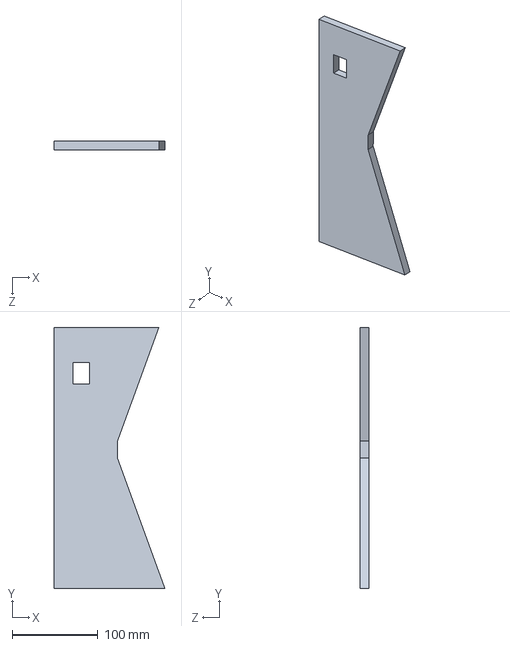
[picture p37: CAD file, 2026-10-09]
mechanical/Playfield/cover_hide.SLDPRT
129.5 x 304.8 x 10.0 mm

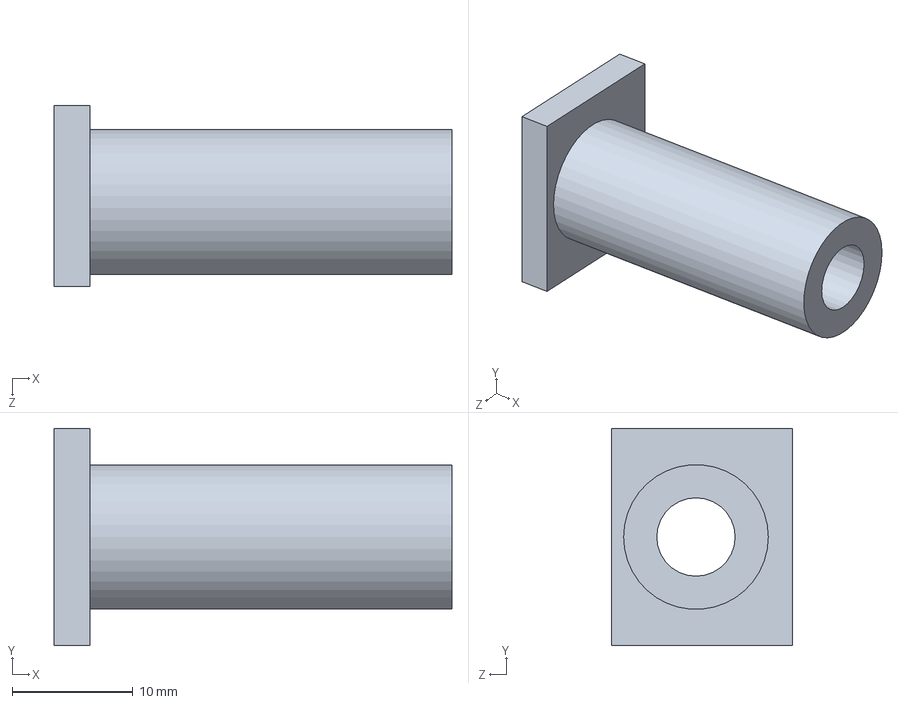
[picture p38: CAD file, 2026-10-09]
mechanical/Plunger/plunger_wall.SLDPRT
33.0 x 18.0 x 15.0 mm

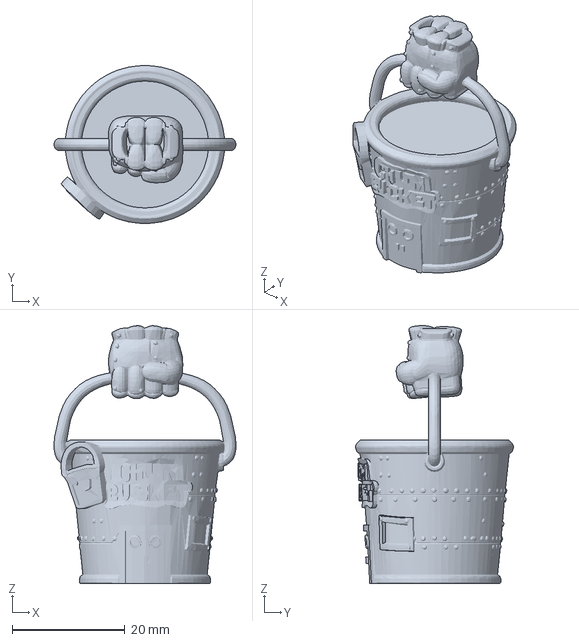
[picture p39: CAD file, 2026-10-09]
mechanical/printed-figures/chum-bucket.3mf
32.2 x 28.0 x 45.7 mm

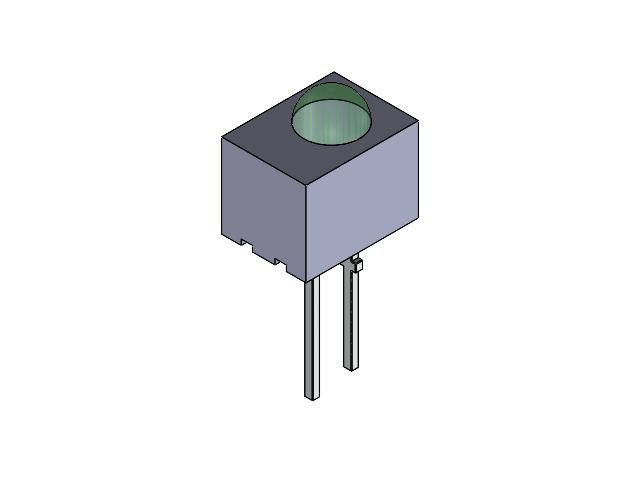
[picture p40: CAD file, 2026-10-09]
mechanical/LEDs/assembled_LED.SLDASM
LED
LED_holder

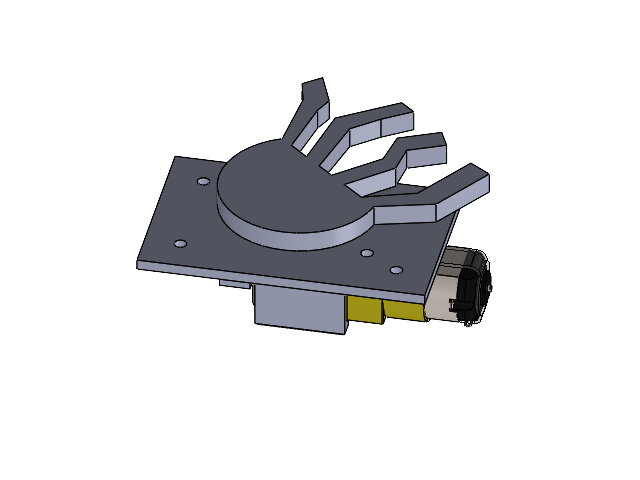
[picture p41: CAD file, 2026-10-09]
mechanical/Motor/assembly_motor.SLDASM
motor
motor-mount
mock_jellyfish
motor_connect

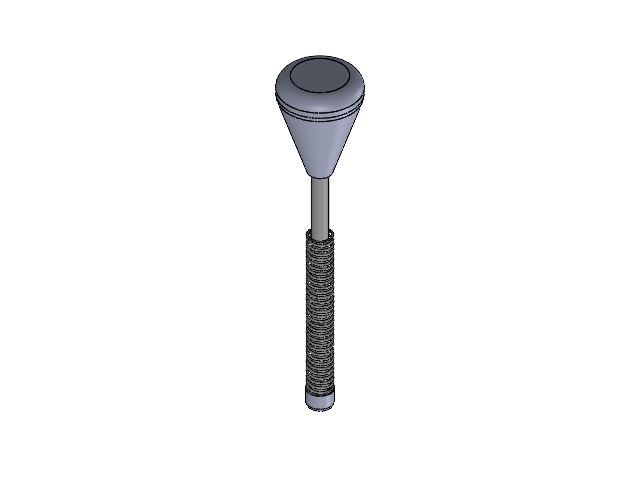
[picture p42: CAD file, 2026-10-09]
mechanical/Plunger/assembly_plunger_Eric_Maddux.SLDASM
tip_plunger_Eric_Maddux
handle_plunger_Eric_Maddux
spring_plunger_Eric_Maddux
rod_plunger_Eric_Maddux

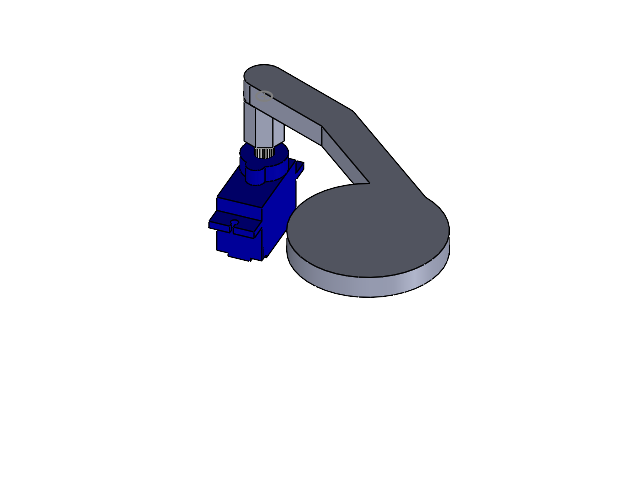
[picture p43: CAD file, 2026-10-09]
mechanical/Krab_Arm/Krab_arm_servo.SLDASM
connector
krab_arm
Pieza1
PZ2

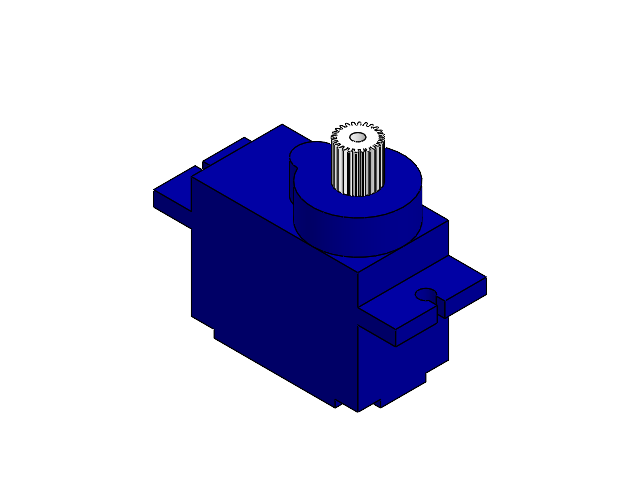
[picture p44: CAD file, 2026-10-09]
mechanical/Krab_Arm/servo.SLDASM
Pieza1
PZ2

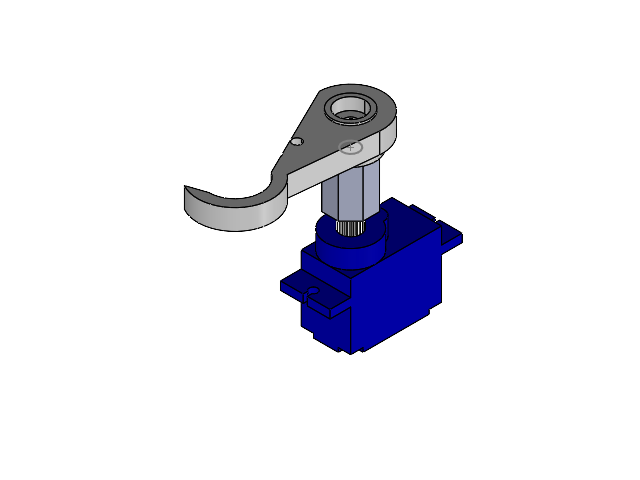
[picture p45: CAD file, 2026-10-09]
mechanical/Krab_Arm/Gating_Mechanism.SLDASM
connector
Pieza1
PZ2
servo_arm

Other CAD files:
mechanical/assembly_pinball_machine.SLDASM
mechanical/Flipper/assembly_flipper_R.SLDASM
mechanical/Playfield/assembly_playfield.SLDASM
mechanical/Flipper/assembly_flipper_L.SLDASM
mechanical/Display.SLDPRT
mechanical/Flipper/AST_Bearings_R4A-2RS.SLDPRT
mechanical/Flipper/backing.SLDPRT
mechanical/Flipper/clamp.SLDPRT
mechanical/Flipper/paddle.SLDPRT
mechanical/Flipper/pole.SLDPRT
mechanical/Flipper/shaft.SLDPRT
mechanical/Flipper/small_bearing.SLDPRT
mechanical/Flipper/solenoid.SLDPRT
mechanical/Flipper/solenoid_connect.SLDPRT
mechanical/Flipper/solenoid_holder.SLDPRT
mechanical/Houses/patrick.SLDPRT
mechanical/Houses/pinapple.SLDPRT
mechanical/Houses/squidward.SLDPRT
mechanical/Krab_Arm/PZ2.SLDPRT
mechanical/Krab_Arm/connector.SLDPRT
mechanical/Krab_Arm/krab_arm.SLDPRT
mechanical/Krab_Arm/servo_arm.SLDPRT
mechanical/LEDs/LED.SLDPRT
mechanical/Motor/mock_jellyfish.SLDPRT
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

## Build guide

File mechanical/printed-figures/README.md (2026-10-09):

# 3D-print figures

This folder contains the original `.3mf` print files supplied with the team's project archive. They are **separate from the SolidWorks mechanical assemblies** in the parent folder.

Some character models may have been sourced from outside the project. **Verify each file's original license and attribution before redistributing or reusing it publicly.** Inclusion here does not imply the team created every themed figure or owns the underlying character IP.

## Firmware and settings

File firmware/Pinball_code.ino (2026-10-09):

#include <Servo.h>
#include "DFRobotDFPlayerMini.h"
bool running = true;
#define mySerial Serial1

// Output Pins
const int MOTOR_PIN = 4;
const int GATE_SERVO_PIN = 5; //Done
const int KRAB_SERVO_PIN = 23; //Done
const int FLIPPER_L_PIN = 2; //Done
const int FLIPPER_R_PIN = 8; //Done
const int DS_PIN = 11;
const int STCP_PIN = 12;
const int SHCP_PIN = 13;
const int SCREEN1_PIN = 10;
const int SCREEN2_PIN = 9;

// Input Pins
const int KRAB_LED_PIN = 3; //Done
const int GATE_LED_PIN = 22; //Done
const int PIEZO1_PIN = A0;  //Done
const int PIEZO2_PIN = A1;  //Done
const int BUTTON_L_PIN = 40; //Done
const int BUTTON_R_PIN = 47; //Done

Servo gateServo;
int gateServoAngle;
Servo krabServo;
int krabServoAngle;

DFRobotDFPlayerMini myDFPlayer;

const unsigned long debounceDelay = 20;

void setup() {
  Serial.begin(115200);
  mySerial.begin(9600);
  // Servo
  gateServo.attach(GATE_SERVO_PIN);
  gateServo.write(0);
  krabServo.attach(KRAB_SERVO_PIN);
  krabServo.write(0);
  Serial.println("Servo Connected");
  // Inputs
  pinMode(KRAB_LED_PIN, INPUT_PULLUP);
  pinMode(GATE_LED_PIN, INPUT_PULLUP);
  pinMode(PIEZO1_PIN, INPUT);
  pinMode(PIEZO2_PIN, INPUT);
  pinMode(BUTTON_L_PIN, INPUT_PULLUP);
  pinMode(BUTTON_R_PIN, INPUT_PULLUP);
  Serial.println("Inputs Connected");
  // Outputs
  pinMode(MOTOR_PIN, OUTPUT);
  pinMode(FLIPPER_L_PIN, OUTPUT);
  pinMode(FLIPPER_R_PIN, OUTPUT);
  pinMode(DS_PIN, OUTPUT);
  pinMode(STCP_PIN, OUTPUT);
  pinMode(SHCP_PIN, OUTPUT);
  pinMode(SCREEN1_PIN, OUTPUT);
  pinMode(SCREEN2_PIN, OUTPUT);


  // Check if the module is responding and if the SD card is found
  Serial.println();
  Serial.println(F("DFRobot DFPlayer Mini"));
  Serial.println(F("Initializing DFPlayer module ... Wait!"));

  if (!myDFPlayer.begin(mySerial)) {
    Serial.println("DFPlayer not detected");
    while(true);
  }
  myDFPlayer.setTimeOut(500);  // Serial timeout 500ms
  myDFPlayer.volume(100);        // Volume 5
  myDFPlayer.EQ(0);            // Normal equalization

  Serial.println("System Ready.");
}
int displayVal = 0;
int point = 0;
int round_count = 0;

void piezo_points(int piezo1, int piezo2){
  if(piezo1 > 150){
    point += 1;
    myDFPlayer.playFolder(1, 003);
  }
  if(piezo2 > 20){
    point += 1;
    myDFPlayer.playFolder(1, 001);
  }
}

// int piezoThresh = 950;
// unsigned long lastDebounceTime_piezo1 = 0;
// int lastSteadyState_piezo1 = LOW;
// int lastRawState_piezo1 = LOW;
// void control_piezo(int piezoNo, int piezoVal){
//   if(piezoNo == 1){
//     if(piezoVal > piezoThresh)
// if (input != lastRawState_LED_gate) {
//     lastDebounceTime_LED_gate = millis(); // Reset timer
//   }
//   if ((millis() - lastDebounceTime_LED_gate) > debounceDelay) {
//     if (input != lastSteadyState_LED_gate) {
//       lastSteadyState_LED_gate = input;
//       if (lastSteadyState_LED_gate == HIGH) {
//         round_count += 1;
//         gate_timer = millis();
//         if(round_count >= 3){
//           gateServo.write(180);
//           gate_timer = millis();
//         }else{
//           gateServo.write(0);
//           gate_timer = millis();
//         }
//       }
//     }
//   }
//   lastRawState_LED_gate = input;
//   }
//   if(piezoNo == 2){

//   }
// }

void loop() {
  int buttonL_sense = digitalRead(BUTTON_L_PIN);
  int buttonR_sense = digitalRead(BUTTON_R_PIN);
  int krab_LED_sense = digitalRead(KRAB_LED_PIN);
  int gate_LED_sense = digitalRead(GATE_LED_PIN);
  int piezo1_sense = analogRead(PIEZO1_PIN);
  int piezo2_sense = analogRead(PIEZO2_PIN);
  if(buttonL_sense == LOW && buttonR_sense == LOW && gate_LED_sense == HIGH){
    running = true;
    restart();
  }
  if(running){
    control_run();
    control_gate(gate_LED_sense);
    control_button_L(buttonL_sense);
    control_button_R(buttonR_sense);
    control_krab_arm(krab_LED_sense);
    digitalWrite(MOTOR_PIN, 2);
    piezo_points(piezo1_sense, piezo2_sense);

    writeToScreen(point);
    if(point >= 100){ 
      point = 0; 
      running = false;
    } // end game, plays a sound, then stops the running

    // Serial.print("Piezo1:");
    // Serial.println(piezo1_sense);
    // Serial.print("Piezo2:");
    Serial.println(gate_LED_sense);
    // Serial.print("LED:");
    // Serial.println(buttonL_sense);
    // Serial.print("---------------------points--------------------");
    // Serial.println(point);




    delay(10);
  }else{// to start press both bottom at once
    if(buttonL_sense == LOW && buttonR_sense == LOW && gate_LED_sense == HIGH){
      running = true;
      restart();
    }
    writeToScreen(0);
  }
}

// Serial force stop code
void control_run(){
  if (Serial.available() > 0) {
    char incomingByte = Serial.read(); // Read the incoming byte
    // Check if the character is 'S' (for Stop)
    if (incomingByte == 'S') {
      running = false; // Set the flag to false to stop the process
      Serial.println("Stop command received. Program paused.");
    }
    // Check if the character is 'R' (for Run/Restart)
    else if (incomingByte == 'R') {
      running = true; // Set the flag to true to resume
      Serial.println("Run command received. Program resumed.");
    }
  }
}

// Display mechanism
int digits [10][8] {
  {0,1,1,1,1,1,1,0}, // 0
  {0,0,1,1,0,0,0,0}, // 1
  {0,1,1,0,1,1,0,1}, // 2
  {0,1,1,1,1,0,0,1}, // 3
  {0,0,1,1,0,0,1,1}, // 4
  {0,1,0,1,1,0,1,1}, // 5
  {0,1,0,1,1,1,1,1}, // 6
  {0,1,1,1,0,0,0,0}, // 7
  {0,1,1,1,1,1,1,1}, // 8
  {0,1,1,1,1,0,1,1}, // 9
};
int dec_digits [10] {126,48,109,121,51,91,95,112,127,123};
void writeToScreen(int value){
  int tens = value/10;
  int ones = value%10;
  digitalWrite(SCREEN1_PIN, HIGH);
  digitalWrite(SCREEN2_PIN, LOW);
  digitalWrite(STCP_PIN,LOW);
  shiftOut(DS_PIN, SHCP_PIN, LSBFIRST, dec_digits[tens]);
  digitalWrite(STCP_PIN,HIGH);
  delay(5);
  digitalWrite(SCREEN1_PIN, LOW);
  digitalWrite(SCREEN2_PIN, HIGH);
  digitalWrite(STCP_PIN,LOW);
  shiftOut(DS_PIN, SHCP_PIN, LSBFIRST, dec_digits[ones]);
  digitalWrite(STCP_PIN,HIGH);
  delay(5);
}

// Gating mechanism
unsigned long lastDebounceTime_LED_gate = 0;
int lastSteadyState_LED_gate = LOW;
int lastRawState_LED_gate = LOW;

unsigned long gate_timer = 0;
void control_gate(int input){
  if (input != lastRawState_LED_gate) {
    lastDebounceTime_LED_gate = millis(); // Reset timer
  }
  if ((millis() - lastDebounceTime_LED_gate) > debounceDelay) {
    if (input != lastSteadyState_LED_gate) {
      lastSteadyState_LED_gate = input;
      if (lastSteadyState_LED_gate == HIGH) {
        round_count += 1;
        gate_timer = millis();
        if(round_count > 3){
          gateServo.write(180);
          gate_timer = millis();
        }else{
          gateServo.write(0);
          gate_timer = millis();
        }
        myDFPlayer.playFolder(1, 004);
      }
    }
  }
  lastRawState_LED_gate = input;
  if(millis() - gate_timer > 1000){
    gateServo.write(180);
  }
  Serial.print("round_count-------------------");
  Serial.println(round_count);
  
}

// Krab mechanism
unsigned long lastDebounceTime_LED_krab = 0;
int lastSteadyState_LED_krab = LOW;
int lastRawState_LED_krab = LOW;
int count_krab = 0;
void control_krab_arm(int input){
  if (input != lastRawState_LED_krab) {
    lastDebounceTime_LED_krab = millis(); // Reset timer
  }
  if ((millis() - lastDebounceTime_LED_krab) > debounceDelay) {
    if (input != lastSteadyState_LED_krab) {
      lastSteadyState_LED_krab = input;
      if (lastSteadyState_LED_krab == HIGH) {
        count_krab += 1;
        point += 1;
        myDFPlayer.playFolder(1, 002);
      }
    }
  }
  lastRawState_LED_krab = input;
  int cases = count_krab%2;
  switch(cases){
    case 0: 
      krabServoAngle = 150;
      break;
    case 1: 
      krabServoAngle = 50;
      break;
  }
  // Serial.println(count_krab);
  krabServo.write(krabServoAngle);
}

// Left Button
unsigned long lastDebounceTime_button_L = 0;
int lastSteadyState_button_L = LOW;
int lastRawState_button_L = LOW;
void control_button_L(int input){
  if (input != lastRawState_button_L) { 
    lastDebounceTime_button_L = millis(); 
  }
  if ((millis() - lastDebounceTime_button_L) > debounceDelay) {
    if (input != lastSteadyState_button_L) {
      lastSteadyState_button_L = input;
      if (lastSteadyState_button_L == HIGH) {
        digitalWrite(FLIPPER_L_PIN, LOW);
        // point += 1;
        delay(10);
      }else{
        digitalWrite(FLIPPER_L_PIN, HIGH);
        delay(10);
      }
    }
  }
    lastRawState_button_L = input;
}

// Right Button
unsigned long lastDebounceTime_button_R = 0;
int lastSteadyState_button_R = LOW;
int lastRawState_button_R = LOW;
void control_button_R(int input){
  if (input != lastRawState_button_R) {
    lastDebounceTime_button_R = millis(); // Reset timer
  }
  if ((millis() - lastDebounceTime_button_R) > debounceDelay) {
    if (input != lastSteadyState_button_R) {
      lastSteadyState_button_R = input;
      if (lastSteadyState_button_R == HIGH) {
        digitalWrite(FLIPPER_R_PIN, LOW);
        delay(10);
      }else{
        digitalWrite(FLIPPER_R_PIN, HIGH);
        delay(10);
      }
    }
  }
    lastRawState_button_R = input;
}

void restart(){
    krabServo.write(0);
    gateServo.write(180);
    digitalWrite(MOTOR_PIN, 10);
    round_count = 0;
    point = 0;
    displayVal = 0;
    count_krab = 0;
    gateServo.write(150);
    delay(50);
    gateServo.write(180);

}
